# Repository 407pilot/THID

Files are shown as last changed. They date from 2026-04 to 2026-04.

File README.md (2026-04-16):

# THID: Tormach Human Interface Device

The THID was created by Austin Allred of [EntirelyCrimson.com](http://entirelycrimson.com) and originally released in 2017 as an open source project. The original files are no longer available from that site; this repository preserves and continues the project. The Arduino sketch has been updated from Austin's original release; the original sketch has been preserved unchanged in the `archive` folder for reference.

> ## WARNING

**This device does not replace a hardware emergency stop.** A software pendant cannot guarantee a response in the event of a program fault, electrical failure, or communication loss. Every CNC machine must have a dedicated hardwired E-stop that cuts power to the drives independently of any software or USB device. Do not use this pendant as a substitute for one.

By building and using this device you accept all risk. No warranty is expressed or implied. The authors are not responsible for damage to equipment, workpieces, or injury resulting from its use.

As of 4/16/2026 the new code is untested on hardware. Please use it with caution. This note will be removed once testing is complete.

## What It Is

The THID is a compact physical control pendant for Tormach's PathPilot CNC controller, but could work with any controller that will accept a USB HID keyboard. It consists of an aluminum housing populated with an Arduino Micro clone and up to four buttons. When a button is pressed, the Arduino emulates a USB keyboard and sends a keystroke combination to the host PC, triggering the corresponding PathPilot action.

The default four-button configuration controls:

| Button | Action | Keystroke |
|---|---|---|
| Cycle Start | Begin program execution | Alt+R |
| Feed Hold | Pause execution | Space |
| Cycle Stop | Abort / emergency stop | Esc |
| Coolant | Toggle coolant on/off | Alt+F |

## Requirements

### Hardware
- Any Arduino-compatible board with native USB HID support (Arduino Leonardo, Micro, Pro Micro, RP2040-based boards, or equivalent clones)
- Momentary pushbutton switches (normally open)
- Buttons wired between the assigned pin and GND; the internal pullup resistor is used, no external resistor needed

### Software
- [Arduino IDE](https://www.arduino.cc/en/software)
- [Bounce2 library](https://github.com/thomasfredericks/Bounce2) - install via Arduino Library Manager (Sketch -> Include Library -> Manage Libraries -> search "Bounce2")

## Wiring

Buttons are wired between the designated pin and GND. Do not wire buttons to 5V; the sketch uses `INPUT_PULLUP`, which holds each pin HIGH internally. Pressing a button pulls the pin LOW, which triggers the action.

Default pin assignments (edit the pin definitions at the top of the sketch to change them):

| Button | Pin |
|---|---|
| Cycle Start | 2 |
| Feed Hold | 3 |
| Cycle Stop | 6 |
| Coolant | 9 |

## Customization

### Remapping buttons to different keystrokes

Each button action is defined in a single line at the bottom of `loop()`. The `sendKey()` helper takes two arguments: a modifier key and a primary key.

```cpp
if (buttons[BTN_CYCLE_START].fell()) sendKey(0x82, 'r');   // Alt+R
if (buttons[BTN_FEEDHOLD].fell())    sendKey(0,    0x20);  // Space
if (buttons[BTN_CYCLE_STOP].fell())  sendKey(0,    0xB3);  // Esc
if (buttons[BTN_COOLANT].fell())     sendKey(0x82, 'f');   // Alt+F
```

To send a keystroke with no modifier, pass `0` as the first argument. ASCII characters (letters, numbers, symbols) can be written as literals: `'r'`, `'f'`, `'1'`, etc.

Common modifier keycodes:

| Modifier | Code |
|---|---|
| Left Alt | `0x82` |
| Left Ctrl | `0x81` |
| Left Shift | `0x80` |
| None | `0` |

Common special key codes:

| Key | Code |
|---|---|
| ESC | `0xB3` |
| Space | `0x20` |
| Enter | `0xB0` |
| Tab | `0xB3` |
| F1-F12 | `0xC2`-`0xCD` |

A full HID keycode reference can be found [here](https://www.usb.org/sites/default/files/hut1_3_0.pdf) (Section 10, Keyboard/Keypad Page).

### Adding or removing buttons

1. Add or remove a pin definition at the top of the sketch.
2. Update the `buttonPins[]` array and `NUM_BUTTONS` constant to match.
3. Add or remove the corresponding entry in the `ButtonIndex` enum.
4. Add or remove the corresponding `if` statement in `loop()`.

### Adjusting debounce timing

The debounce interval is set to 10ms by default, which is appropriate for most switches. If you experience double-triggering with a specific switch, increase the value in `setup()`:

```cpp
buttons[i].interval(10);  // increase if double-triggers are observed
```

## Bill of Materials

| Qty | Item | Notes | Link |
|---|---|---|---|
| 1 | Arduino Micro or compatible clone | Must support native USB HID (see note below) | [https://amzn.to/4cnrPwq](https://amzn.to/4cnrPwq) |
| 1 | Aluminum housing | Use provided solid models for fabrication | |
| 4 | 19mm momentary pushbutton, stainless steel | Normally open; LED illuminated versions also fit | [https://amzn.to/4sDTDmv](https://amzn.to/4sDTDmv) |
| 4 | 20mm x 3mm round magnets | 20mm x 2mm magnets will work as well; retain with CA glue or Green Loctite | [https://amzn.to/3O4Rzpr](https://amzn.to/3O4Rzpr) |
| 4 | M3-0.5 x 25mm button head screw | Substitute for screw of your choice by modifying the solid model | [https://amzn.to/4mrWXiS](https://amzn.to/4mrWXiS) |

> **Disclosure:** The links above are Amazon affiliate links. Purchases made through them may provide a small commission at no additional cost to you.

### RP2040 boards

RP2040-based boards (such as the Raspberry Pi Pico and its clones) support USB HID but require the [Earle Philhower arduino-pico core](https://github.com/earlephilhower/arduino-pico) rather than the standard Arduino AVR core. To install it, add the following URL to **File -> Preferences -> Additional Boards Manager URLs** in the Arduino IDE, then install **Raspberry Pi Pico/RP2040 by Earle F. Philhower, III** from the Boards Manager:

```
https://github.com/earlephilhower/arduino-pico/releases/download/global/package_rp2040_index.json
```

AVR-based boards (Leonardo, Micro, Pro Micro) do not require this step.

## LED Lighting

The sketch does not currently control the button LEDs, but there is no reason this cannot be added. If you choose illuminated switches, note that the linked buttons do not include a current limiting resistor; you will need to calculate and add the correct resistor for whatever voltage you use. This applies whether you are powering the LEDs from a dedicated power pin or driving them directly from a digital output pin. AVR-based boards (Micro, Pro Micro, Leonardo) output 5V on their digital pins, while most newer boards including RP2040-based clones output 3.3V. Use the correct voltage for your board when sizing your resistor.

## Notes

- The sketch sends keystrokes to whatever application has focus on the host PC. Ensure PathPilot has focus before using the pendant.
- The device presents itself as a standard USB HID keyboard; no drivers are required on the host PC.

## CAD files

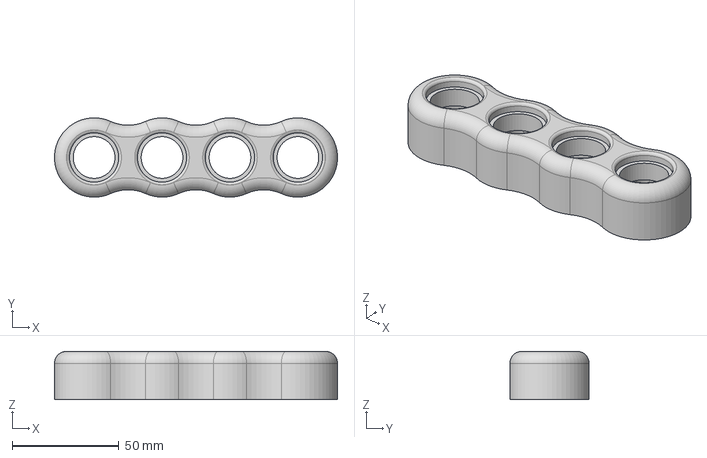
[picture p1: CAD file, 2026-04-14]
Solid Model/THID Housing Lid.step
132.3 x 37.0 x 22.6 mm

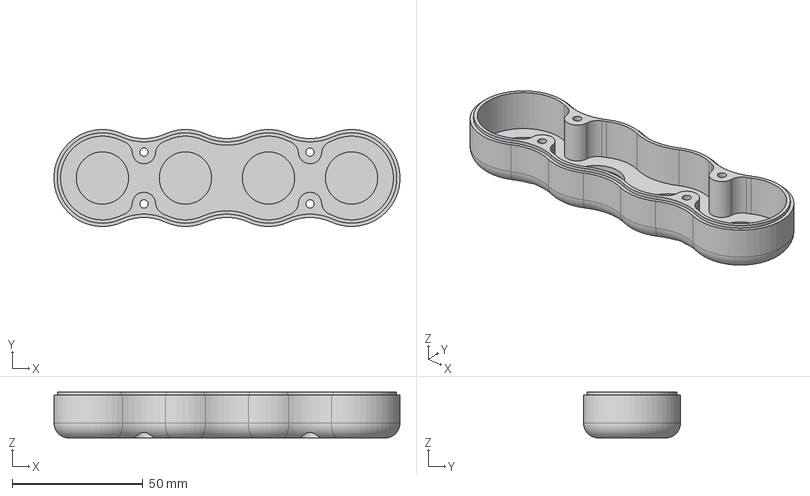
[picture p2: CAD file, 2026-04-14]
Solid Model/THID Housing Back.step
132.3 x 37.0 x 17.5 mm

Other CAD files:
Solid Model/THID_Housing.f3d

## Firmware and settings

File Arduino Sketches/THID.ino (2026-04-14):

// ============================================================
// Doug Craig, 2026
// https://github.com/407pilot/THID
//
// Compatible with any Arduino board that supports native USB HID:
// Leonardo, Micro, Pro Micro, Zero, MKR series, RP2040, etc.
//
// Required library: Bounce2 (available in Arduino Library Manager)
//
// Raw HID keycodes are used instead of named constants to ensure
// compatibility across all board packages and cores.
//
// HID Keycode Reference (used in this sketch):
//   0x82 = Left Alt
//   0x81 = Left Ctrl
//   0xB3 = ESC
//   0x20 = Space
//   'r'  = R key (ASCII literals are always safe)
//   'f'  = F key (ASCII literals are always safe)
// ============================================================

#include <Keyboard.h>
#include <Bounce2.h>

// --- Pin Definitions ---
const int PIN_CYCLE_START = 2;
const int PIN_FEEDHOLD    = 3;
const int PIN_CYCLE_STOP  = 6;
const int PIN_COOLANT     = 9;

const int NUM_BUTTONS = 4;
const int buttonPins[NUM_BUTTONS] = {
  PIN_CYCLE_START, PIN_FEEDHOLD, PIN_CYCLE_STOP, PIN_COOLANT
};

// --- Button Index Names ---
enum ButtonIndex {
  BTN_CYCLE_START = 0,
  BTN_FEEDHOLD,
  BTN_CYCLE_STOP,
  BTN_COOLANT
};

Bounce buttons[NUM_BUTTONS];

// --- Helper: send an optional modifier + key, then release ---
void sendKey(uint8_t modifier, uint8_t key) {
  if (modifier) Keyboard.press(modifier);
  Keyboard.press(key);
  delay(10);
  Keyboard.releaseAll();
}

void setup() {
  for (int i = 0; i < NUM_BUTTONS; i++) {
    pinMode(buttonPins[i], INPUT_PULLUP);
    buttons[i].attach(buttonPins[i]);
    buttons[i].interval(10);  // 10ms debounce
  }
  Keyboard.begin();
}

void loop() {
  for (int i = 0; i < NUM_BUTTONS; i++) {
    buttons[i].update();
  }

  if (buttons[BTN_CYCLE_START].fell()) sendKey(0x82, 'r');   // Alt+R
  if (buttons[BTN_FEEDHOLD].fell())    sendKey(0,    0x20);  // Space
  if (buttons[BTN_CYCLE_STOP].fell())  sendKey(0,    0xB3);  // Esc
  if (buttons[BTN_COOLANT].fell())     sendKey(0x82, 'f');   // Alt+F
}
